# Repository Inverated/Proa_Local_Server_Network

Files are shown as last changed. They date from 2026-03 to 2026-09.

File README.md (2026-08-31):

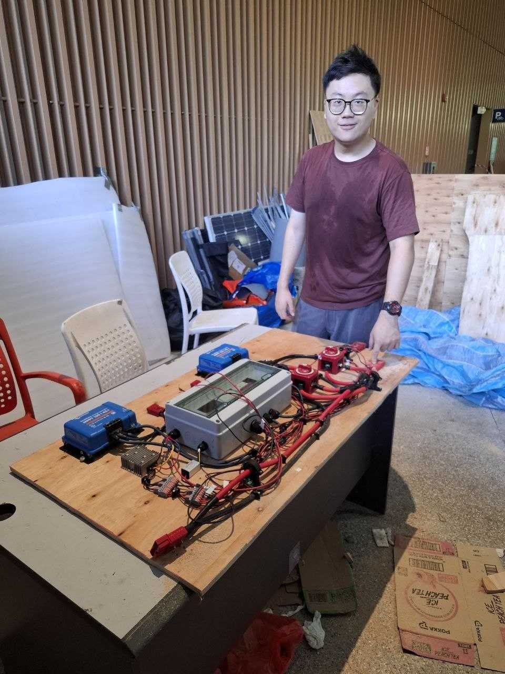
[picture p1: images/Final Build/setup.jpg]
Proa Local Server Network Hardware Setup


# Hardware

Electrical simulation used for the build can be found at [Solar Proa](https://github.com/shipshape-marine/solar-proa/tree/main/src/electrical_simulation).

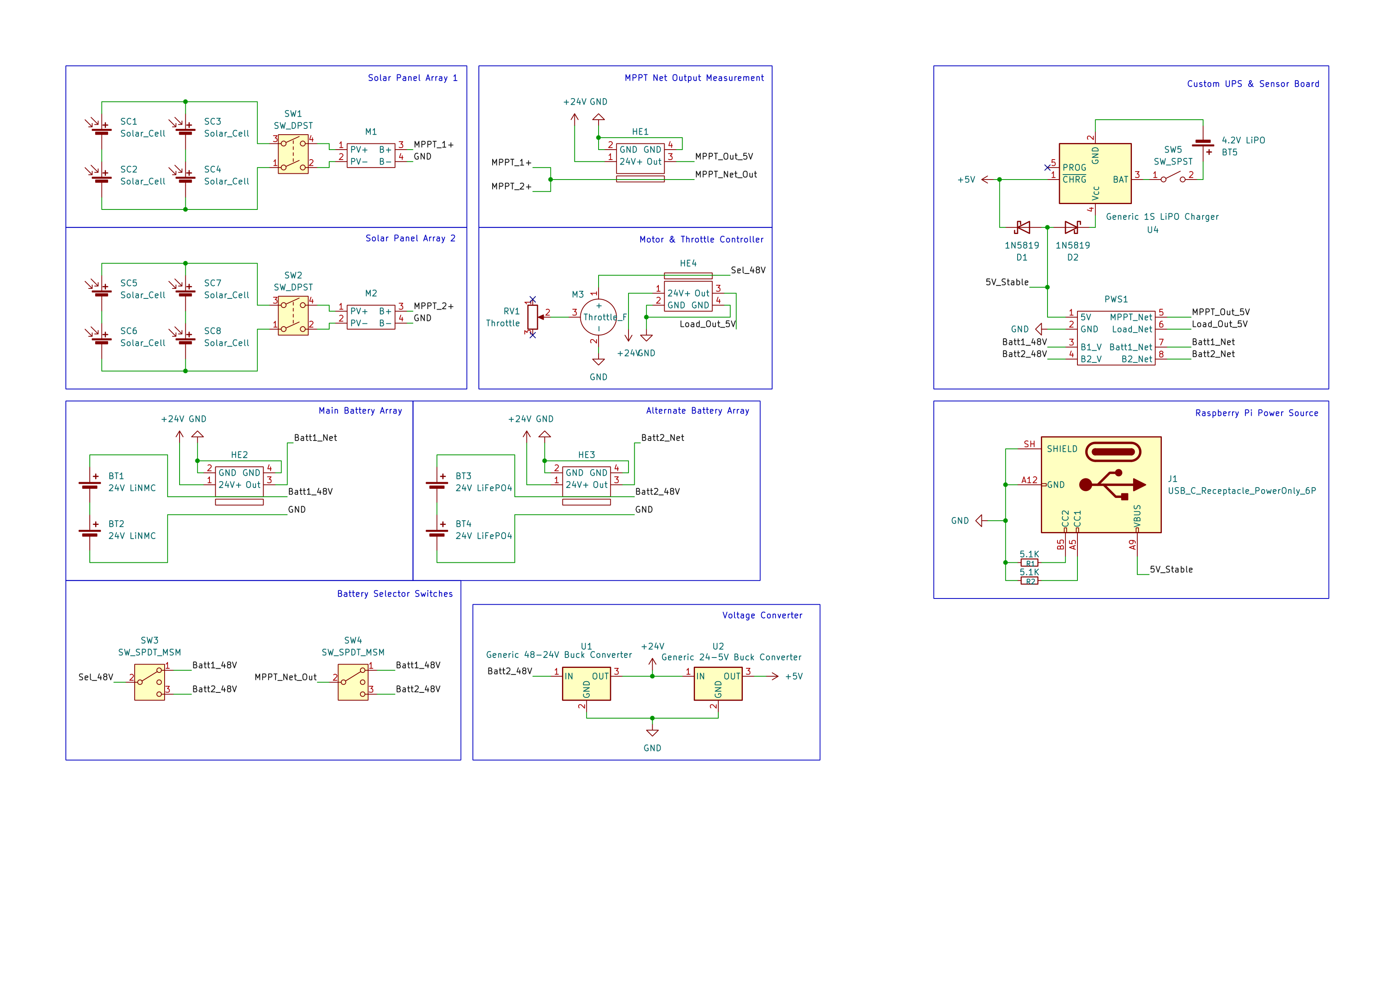
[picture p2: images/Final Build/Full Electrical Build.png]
Proa Local Server Network Schema


KiCad build file [here](./Hardware%20Schematics/ADC%20Power%20Sensor%20Design/).

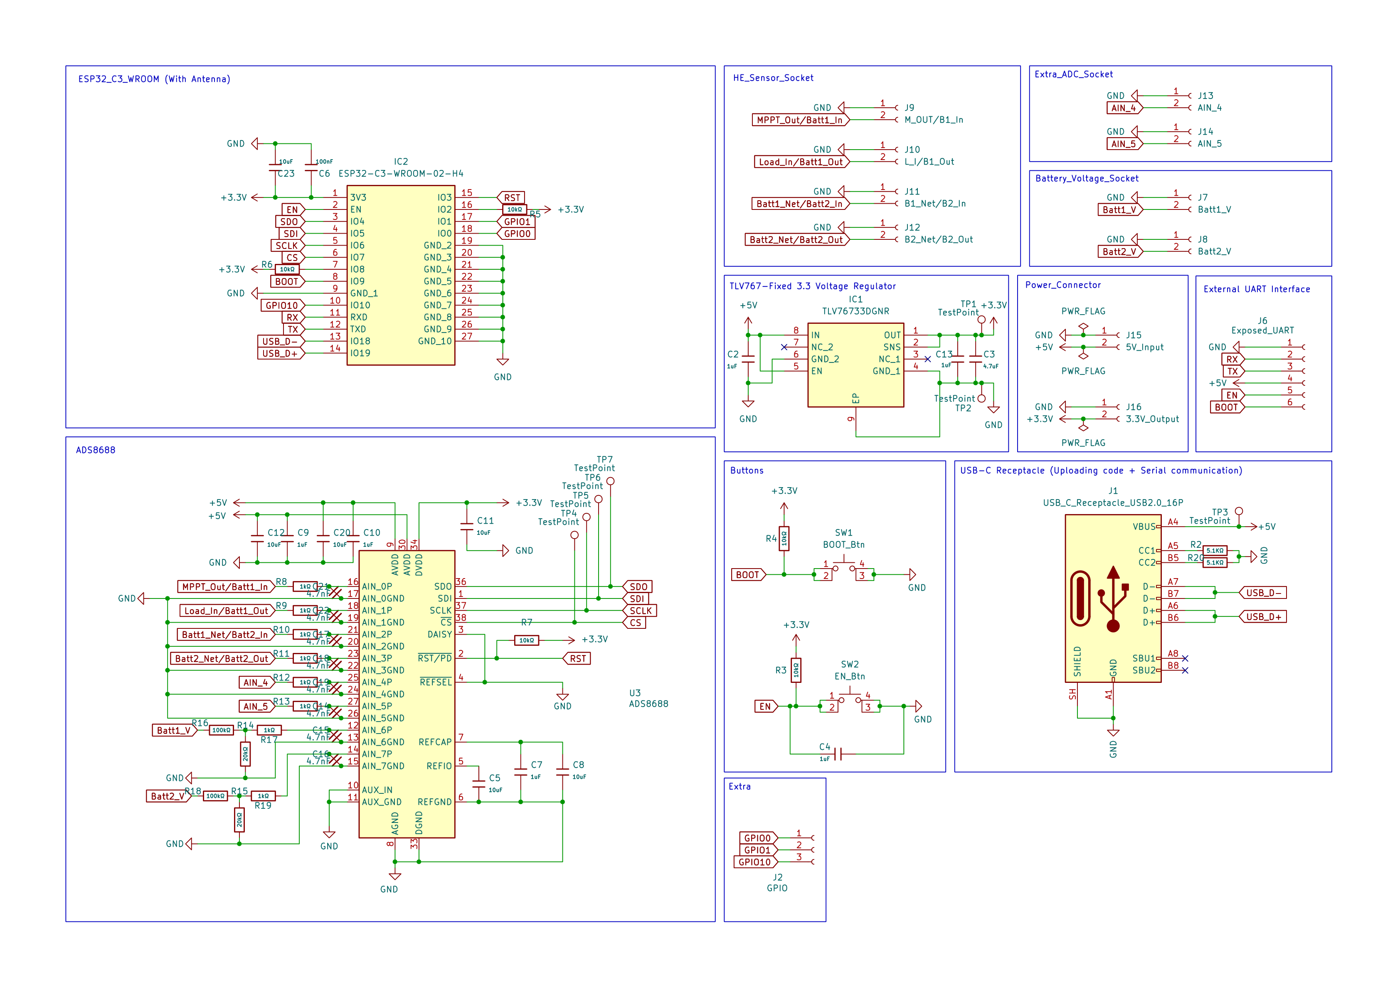
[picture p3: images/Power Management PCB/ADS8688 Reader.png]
Power Management Board


# Framework

Network of ESP32 microcontrollers with a Raspberry Pi 4 acting as a local server. ESP32 reading the sensors (slave) communicates bi-directionally via ESP-NOW where the main (Master) ESP32 sends the data to the raspberry pi via Serial communication.

ESP-NOW used for its low latency and low power consumption while being very easy to setup (<10 lines to setup + 2 function that runs when receiving or sending data), while Serial is used for its reliability and ease of use.

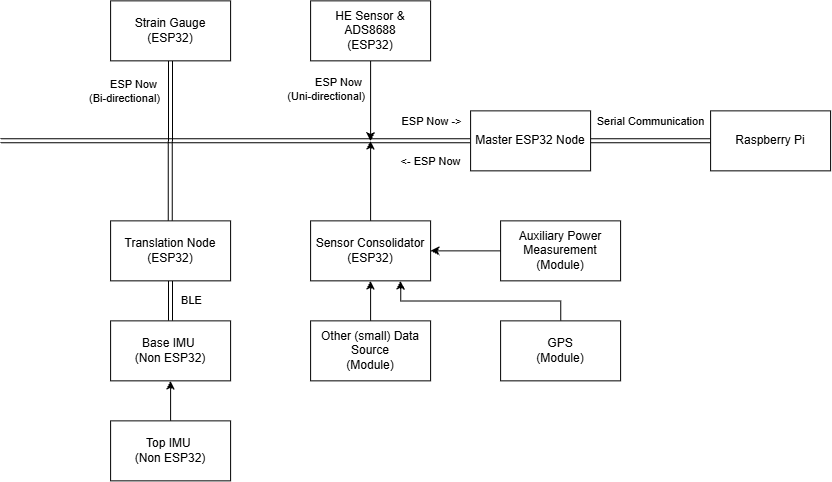
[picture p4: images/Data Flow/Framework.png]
Proa Local Server Network Framework


Both Serial and ESP-NOW allows for bi-communication, allowing the raspberry pi to send command (zeroing, start, stop, etc.) to specific ESP32s (IMU), while the ESP32s sends data to the raspberry pi at the same time.

[Template for communicating with the master node](./firmware/ESP32/template_sender_firmware//). Note that the mac address need to be changed to the master node's mac address in order for the ESP32 to send data to the master node.

# Code Structure

ExpressJs backend api + Serial reading

React frontend with MUI dashboard template

- https://github.com/mui/material-ui/tree/v9.0.1/docs/data/material/getting-started/templates/dashboard
- A shit template that mixes ts, js and tsx, jsx and poor code organisation

# Proa Local Server Network — Step by step Setup Guide

## Part 1: Running the App

1. `cd` into `PROA_LOCAL_SERVER_NETWORK`.
2. Ensure npm is installed on your system.
3. Run `npm run install:yarn`.
4. Run `yarn start:all`.
   - This automatically builds the React app and runs it with Node.js.
5. Open `http://localhost:4000` in your browser.
6. Dev panel access: username=admin   password=admin

---

## Part 2: Raspberry Pi 4 Setup (Everything else after this is for setting up on raspberry pi)

Using Raspberry Pi Lite OS for fast boot time in case of downtime.
> A UPS is included, but fast boot time and proper recovery steps are still essential.

### 2.1 Initial Setup (from a fresh install via Raspberry Pi Imager)

If ssh does not work, you may need to connect the Pi to an external screen and keyboard to enable it.
1. Connect the Pi to an external screen (micro HDMI) and keyboard.
2. Log in with the username and password created during Imager setup.
3. Enable and start SSH:
   ```bash
   sudo systemctl enable ssh
   sudo systemctl start ssh
   ```

### 2.2 SSH into the Pi from Another Computer

1. On Raspberry Pi 4 and below (check your model first), the USB-C port is power-only — you'll need an additional Ethernet cable to connect.

### 2.3 Optimize Boot Time

1. Open the quick system settings GUI to connect to a WiFi network for update purposes:
   ```bash
   sudo raspi-config
   ```
2. Disable unneeded services for a faster boot:
   ```bash
   sudo systemctl disable NetworkManager-wait-online.service
   sudo systemctl mask NetworkManager-wait-online.service
   sudo systemctl disable cloud-init-local.service
   sudo systemctl disable cloud-init-main.service
   sudo systemctl disable cloud-config.service
   sudo systemctl disable cloud-final.service
   sudo systemctl disable apt-daily-upgrade.service
   sudo systemctl disable apt-daily.service
   ```
3. Note: boot time will still be around 20 seconds.

### 2.4 Verify Network Connectivity (Before Upgrading Packages)
 
`apt full-upgrade` requires a working internet connection — check this first if you hit connection errors.
 
1. Check if Wi-Fi is scanning networks:
```bash
   sudo iwlist wlan0 scan | grep ESSID
```
2. If nothing comes back (Wi-Fi is down), bring it back up:
```bash
   sudo rfkill unblock wifi
   sudo ip link set wlan0 up
   sudo nmcli radio wifi on
   sudo systemctl restart wpa_supplicant
   sudo systemctl restart NetworkManager
```
3. Re-run the scan command from step 1 to confirm networks now appear, then proceed.

### 2.5 Download Required Packages

1. Update and install system packages:
   ```bash
   sudo apt full-upgrade
   sudo apt install git nodejs npm curl hostapd dnsmasq dhcpcd5 iptables nginx -y
   sudo npm install yarn -g
   ```
2. Install nvm and Node LTS:
   ```bash
   curl -o- https://raw.githubusercontent.com/nvm-sh/nvm/v0.40.1/install.sh | bash
   source ~/.bashrc
   nvm install --lts
   nvm use node
   ```

### 2.6 Set Up the Git Repo

1. Create a directory and clone the repo:
   ```bash
   mkdir apps
   cd apps
   git clone https://github.com/Inverated/Proa_Local_Server_Network advisor
   cd advisor/
   yarn install
   yarn start:all
   ```
2. Force-stop the process once the initial build completes.

3. Copy '.env' into proa_advisor

### 2.7 Set Up the Network (Wi-Fi Access Point)

1. Stop the AP-related services before configuring them:
   ```bash
   sudo systemctl stop hostapd
   sudo systemctl stop dnsmasq
   ```
2. Mark `wlan0` as unmanaged by NetworkManager. Edit:
   ```bash
   sudo nano /etc/NetworkManager/conf.d/unmanaged.conf
   ```
   Add:
   ```ini
   [keyfile]
   unmanaged-devices=interface-name:wlan0
   ```
3. Set a static IP for `wlan0`. Edit:
   ```bash
   sudo nano /etc/dhcpcd.conf
   ```
   Add:
   ```ini
   interface wlan0
   static ip_address=192.168.4.1/24
   nohook wpa_supplicant
   ```
4. Restart the dhcpcd service:
   ```bash
   sudo systemctl restart dhcpcd
   ```
5. Configure hostapd. Edit:
   ```bash
   sudo nano /etc/hostapd/hostapd.conf
   ```
   Add:
   ```ini
   interface=wlan0
   driver=nl80211

   ssid=Proa_II

   hw_mode=g
   channel=6

   country_code=SG

   wmm_enabled=1

   auth_algs=1
   ignore_broadcast_ssid=0

   wpa=2
   wpa_passphrase=password

   wpa_key_mgmt=WPA-PSK
   rsn_pairwise=CCMP
   ```
6. Point the hostapd daemon at that config. Edit:
   ```bash
   sudo nano /etc/default/hostapd
   ```
   Add:
   ```ini
   DAEMON_CONF="/etc/hostapd/hostapd.conf"
   ```
7. Back up and replace the dnsmasq config:
   ```bash
   sudo mv /etc/dnsmasq.conf /etc/dnsmasq.conf.orig
   sudo nano /etc/dnsmasq.conf
   ```
   Add:
   ```ini
   interface=wlan0

   dhcp-range=192.168.4.2,192.168.4.100,255.255.255.0,24h

   dhcp-option=3,192.168.4.1
   dhcp-option=6,192.168.4.1

   address=/#/192.168.4.1
   ```
8. Unmask and enable the AP services, then restart networking and start them:
   ```bash
   sudo systemctl unmask hostapd
   sudo systemctl enable hostapd
   sudo systemctl enable dnsmasq

   sudo systemctl restart wpa_supplicant
   sudo systemctl restart NetworkManager
   sudo systemctl start hostapd
   sudo systemctl start dnsmasq
   ```
9. Verify `wlan0` is running in AP mode:
    ```bash
    iw dev wlan0 info
    ```
    If the type isn't `AP`, run `sudo reboot` and check again.

10. Give access to user to run nmcli over Node
    ```bash
    sudo nano /etc/polkit-1/rules.d/50-nmcli.rules
    ```
    Add:
    ```javascript
    polkit.addRule(function(action, subject) {
        if (action.id.indexOf("org.freedesktop.NetworkManager.") === 0 &&
            subject.user == "admin") {
            return polkit.Result.YES;
        }
    });
    ```
11. Restart polkit:
    ```bash
    sudo systemctl restart polkit
    ```

### 2.9 Auto-Redirect Port 80 to the App (Port 4000)

1. Create the redirect service:
   ```bash
   sudo nano /etc/nginx/sites-available/solarproa
   ```
   Add:
   ```ini
   server {
    listen 80;
    server_name solarproa.local;

    location / {
        proxy_pass http://127.0.0.1:4000;

        proxy_set_header Host $host;
        proxy_set_header X-Real-IP $remote_addr;
        proxy_set_header X-Forwarded-For $proxy_add_x_forwarded_for;
        proxy_set_header X-Forwarded-Proto $scheme;
    }
   }
   ```
2. Enable and start it:
   ```bash
   sudo ln -s /etc/nginx/sites-available/solarproa /etc/nginx/sites-enabled/
   ```

3. Test it:
   ```bash
   sudo nginx -t
   ```

4. Restart nginx service
   ```bash
   sudo systemctl restart nginx
   ```

   When connected to the same network as the raspberry pi, go to http://solarproa.local

### 2.8 Set Up Auto-Start on Boot

1. Create the app service:
   ```bash
   sudo nano /etc/systemd/system/solarproa-advisor.service
   ```
   Add:
   ```ini
    [Unit]
    Description=Solar Proa Advisor
    After=network-online.target
    Wants=network-online.target

    [Service]
    Type=simple
    User=admin
    WorkingDirectory=/home/admin/apps/advisor/proa_advisor

    Environment=NODE_ENV=production
    Environment=NVM_DIR=/home/admin/.nvm

    ExecStart=/bin/bash -c 'source "$NVM_DIR/nvm.sh" && nvm use default && exec yarn start'

    Restart=always
    RestartSec=5

    [Install]
    WantedBy=multi-user.target
   ```
2. Enable and start it:
   ```bash
   sudo systemctl daemon-reload
   sudo systemctl enable solarproa-advisor
   sudo systemctl start solarproa-advisor
   ```
3. Check the logs:
   ```bash
   journalctl -u solarproa-advisor -f
   ```

### 2.10 Note: AP vs. Wi-Fi Receiver Mode

The Wi-Fi chip can only act as **either** an access point **or** a receiver at one time — switch back to receiving, or use an external Wi-Fi adapter.

1. Check the new Wi-Fi receiver's interface name (should be `wlan1`).
2. Connect to a network on that interface:
   ```bash
   sudo nmcli device wifi connect "YourSSID" password "YourPassword" ifname wlan1
   ```

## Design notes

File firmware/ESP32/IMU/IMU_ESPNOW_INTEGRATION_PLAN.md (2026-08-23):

# IMU ESP-NOW Integration Plan

## Problem Statement
Replace the standalone BLE-to-browser IMU monitoring system with an ESP-NOW based data path that flows through the existing master node and proa_advisor server, making IMU telemetry available in the proa_advisor_react dashboard alongside the existing power management data.

## Requirements
- Base IMU node sends 28-byte telemetry packets to the master via ESP-NOW using the existing PacketTemplate format
- Base node retains BLE central role to collect gravity data from the nRF52840 top node (unchanged)
- Master node forwards raw bytes to the server (unchanged behavior), plus maintains a `header->MAC` lookup table for routing commands back
- Server parses TELE packets, computes derivable fields, and streams IMU data to the React frontend via SSE
- Command path: server sends `TELE|command\n` over serial -> master resolves TELE->MAC -> sends command to base via ESP-NOW
- Base receives commands via ESP-NOW and handles START/STOP/ZERO/RESET_ZERO
- React frontend displays IMU telemetry in a new "Mast Monitor" page similar to the mast-monitor-pairing-display UI

## Architecture

```
Top Node (nRF52840 Sense, BLE Peripheral)
    |
    | BLE GravityPacket (gx, gy, gz, seq)
    v
Base Node (ESP32, BLE Central + ESP-NOW Sender)
    |
    | ESP-NOW 28-byte TELE packet
    v
Master Node (ESP32, ESP-NOW Hub, USB Serial)
    |
    | Serial.write(raw bytes)
    v
proa_advisor (Node.js Server)
    |
    | SSE 'imu' event
    v
proa_advisor_react (Dashboard)

Command path (reverse):
Dashboard -> POST /command/imu -> Server -> Serial "TELE|cmd\n" -> Master -> ESP-NOW -> Base
```

## Packet Structure (28 bytes)

```c
struct __attribute__((packed)) Telemetry_Payload {
  int16_t  baseRoll;            // 2 bytes - fixed point x100
  int16_t  basePitch;           // 2 bytes
  int16_t  topRoll;             // 2 bytes
  int16_t  topPitch;            // 2 bytes
  int16_t  topMinusBaseRoll;    // 2 bytes
  int16_t  topMinusBasePitch;   // 2 bytes
  int16_t  vectorAngle;         // 2 bytes
  uint16_t topSeq;              // 2 bytes
  uint8_t  status;              // 1 byte (bit0=topConnected, bit1=sensingEnabled, bit2=zeroReady)
};                              // = 17 bytes

using TelemetryPacket = PacketTemplate<Telemetry_Payload, 3>;
// header(4) + counter(2) + payload(17) + padding(3) + chksum(2) = 28 bytes
```

## Key Design Decisions
- No MAC address in packet: server identifies data by header ("TELE"), master holds header->MAC table internally for command routing
- Top node stays nRF52840 Sense (onboard IMU), BLE link to base unchanged
- Base auto-reconnects to top node every 3 seconds (no PAIR_TOP command needed)
- Commands supported: START, STOP, ZERO, RESET_ZERO
- 28-byte packet size maintained: no changes needed to PACKET_BYTES constant in serial reader
- Derivable fields computed server-side: bendMagnitude, baseMinusTopRoll, baseMinusTopPitch

## Task Breakdown

### Task 1: Base node firmware (BLE to top + ESP-NOW telemetry)
- Update `revised_base_node_v2_esp_now.ino` with new Telemetry_Payload (vectorAngle + status)
- PAD_BYTES changes from 6 to 3
- Serial debug logging for BLE connection, angle computation, ESP-NOW delivery
- Auto-start sensing for testing (sensingEnabled = true by default)
- onDataRecv stub registered for future command reception

### Task 2: Server-side TELE parser (console output)
- Create/update `imu_telemetry_parser.js` 
- Add TELE_HEADER branch in serialReader.js processBuffer()
- Parse 28-byte packet, validate checksum, convert fixed-point to float
- Compute derived fields (bendMagnitude, baseMinusTop)
- Console.log parsed telemetry for verification

### Task 3: Master node header->MAC table + command routing
- Add header->MAC lookup in OnDataRecv
- Modify checkForSerialCommands() to parse "HEADER|command\n" format
- Look up MAC from header table, call sendCommandToNode

### Task 4: Base node command reception via ESP-NOW
- Implement onDataRecv to receive commands from master
- Route to handleCommand() (START/STOP/ZERO/RESET_ZERO)
- Serial debug logging on command receipt

### Task 5: Server SSE streaming + command endpoint
- Call write_to_clients("imu", data) from parser
- Add POST /command/imu endpoint
- Update serial_writer.js to use header instead of MAC

### Task 6: React frontend - Mast Monitor page
- Add "imu" SSE event listener in Dashboard.tsx
- Create MastMonitor component with metrics, tables, status, command buttons
- Define ImuData type

### Task 7: Integration verification
- Full system test with power sensor and IMU running simultaneously
- Verify no packet corruption between types
- Test reconnection scenarios

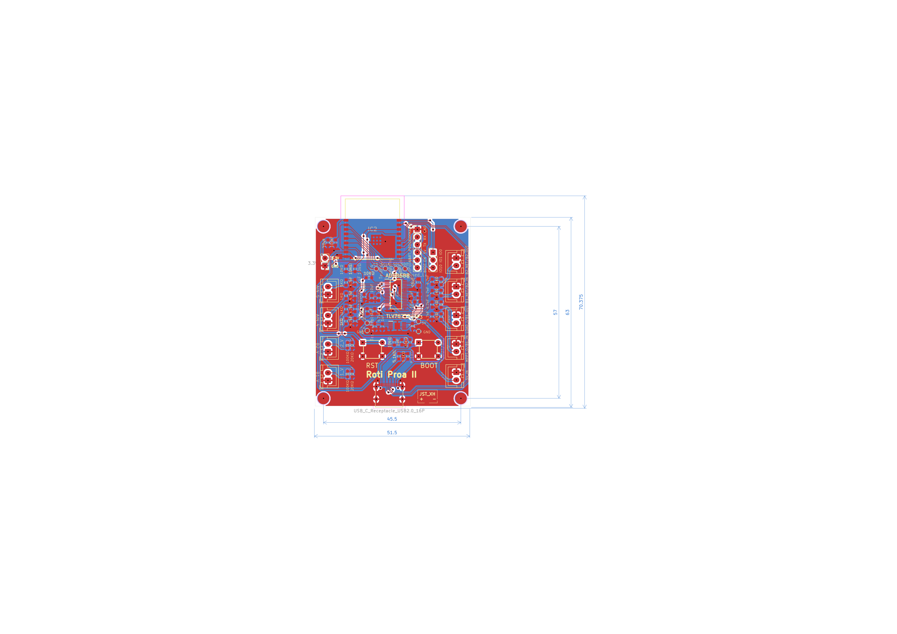
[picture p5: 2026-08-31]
images/Power Management PCB/PCB Schematic.png

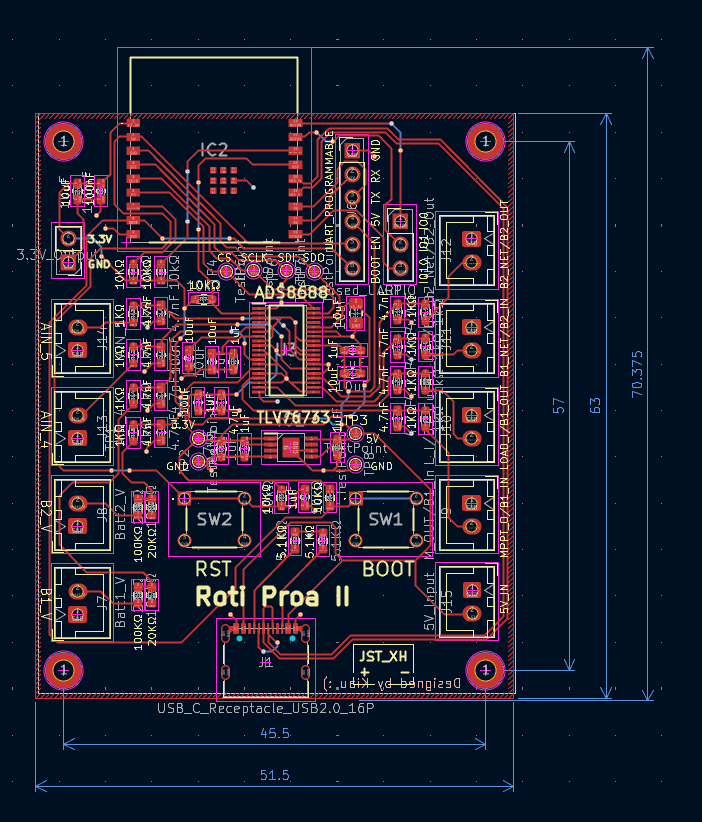
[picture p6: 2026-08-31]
Hardware Schematics/Electrical Schematics/ADC Power Sensor Design/Sensor Reader V4/Screenshot 2026-08-31 162607.png

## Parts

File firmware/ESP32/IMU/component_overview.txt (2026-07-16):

Component overview (location -> purpose)

1) IMU.ino
   Path: firmware\ESP32\IMU\IMU.ino
   Purpose: Simple BLE top-node example that reads LSM6DS3 accel, computes roll/pitch, and advertises them via a BLE characteristic (XIAO_TOP_IMU). Used for broadcasting angle packets.

2) revised_top_node.ino
   Path: mast_monitor_package\firmware\revised_top_node\revised_top_node.ino
   Purpose: Top IMU node. Reads accel, applies a low-pass gravity filter, publishes GravityPacket (gx,gy,gz,seq) over BLE to a base node at ~20Hz.

3) revised_base_node.ino
   Path: mast_monitor_package\firmware\revised_base_node\revised_base_node.ino
   Purpose: Base bridge. Reads base IMU, connects to top node over BLE, subscribes to top gravity packets, filters vectors, computes roll/pitch, zeroing, and exposes telemetry & command BLE service for a browser dashboard (CSV telemetry).

4) top_node_pairing_display.ino
   Path: mast-monitor-pairing-display\arduino\top_node_pairing_display\top_node_pairing_display.ino
   Purpose: Top node variant for pairing/display. Publishes gravity packets and periodic status string characteristic to help pairing and diagnostics.

5) base_bridge_pairing_display.ino
   Path: mast-monitor-pairing-display\arduino\base_bridge_pairing_display\base_bridge_pairing_display.ino
   Purpose: Base bridge variant supporting pairing UI. Scans/connects to top, exposes telemetry, command, and status characteristics to a browser pairing dashboard; supports PAIR/START/STOP/ZERO commands and telemetry CSV output.

6) mast_monitor_package node server
   Path: mast_monitor_package\node_app\server.js
   Purpose: Fastify server serving a simple browser dashboard (public/) and /api/log endpoints to start/stop/append CSV logs (fields: timestamp,baseRoll,basePitch,topRoll,topPitch,deltaRoll,deltaPitch,totalAngle).
   Additional: public app.js implements Web Bluetooth client to connect to XIAO_BASE_BRIDGE, render telemetry, send commands, and call the log API.

7) mast-monitor-pairing-display node server
   Path: mast-monitor-pairing-display\server.js
   Purpose: Fastify server for the pairing/display UI. Serves public UI and richer /api/log endpoints using expanded CSV_FIELDS (includes topMinusBase, bendMagnitude, vectorAngle, topSeq and status fields). Supports CSV escaping.
   Additional: public app.js implements a richer Web Bluetooth UI: pairing, status updates, telemetry parsing, and resilient log append queueing.

Notes:
- package.json files exist under both node app folders (node_app and mast-monitor-pairing-display) defining Node dependencies and start scripts.
- Main components: top IMU nodes (publish filtered gravity vector), base bridge nodes (aggregate, compute angles, expose telemetry & commands), and browser dashboards (connect via Web Bluetooth and log telemetry via local HTTP server).

BLE communication and roles:
- Top node: advertises the gravity characteristic (UUIDs starting with 19B10010/11). It is the broadcaster; it does not initiate connections to the base.
- Base node: actively scans for a device named "XIAO_TOP_IMU", connects, discovers the gravity characteristic, and subscribes to notifications. The base acts as the collector/master for the top node and also reads its own IMU.
- Collector/third device: there is no separate ESP32 that collects from both. The base node collects both top and base IMU data and exposes telemetry to a browser (XIAO_BASE_BRIDGE). The browser (web app) and optional local Node server act as the UI and log collector but are not required for the BLE link between top and base.

Commands from the web app to the ESP32 (written to the command BLE characteristic):
- START: Sent to the base node. Enables sensing and periodic telemetry output on the base. The command itself only affects the base, but effective telemetry output requires both IMUs connected and zeroed (the base will auto-zero if both IMUs are ready).
- STOP: Sent to the base node. Disables sensing and stops telemetry updates on the base. This operates on the base only (no top interaction required to process the command).
- ZERO: Sent to the base node. Captures the current pose as the zero reference for both base and top; requires both IMUs to be ready/connected so the base can read the top packet and compute a joint zero. (Requires interaction with both top and base.)
- PAIR / PAIR_TOP / SCAN: Sent to the base node (pairing-display firmware). Instructs the base to scan for and attempt to connect/pair with the top node. This is a base-initiated action that interacts with the top during pairing.
- RESET_ZERO: Sent to the base node (pairing-display firmware). Clears the stored zero state on the base so a new ZERO can be captured; does not require the top to be connected to execute (base-only).

Web app logging API calls (local Node server):
- POST /api/log/start: Create/open a new CSV log file and return its path.
- POST /api/log/stop: Close the active log file.
- POST /api/log/append: Append a telemetry row (JSON) to the active CSV log. The browser sends telemetry here after decoding BLE notifications.

Where command handling is implemented:
- revised_base_node.ino and base_bridge_pairing_display.ino: handleCommand(...) implements START/STOP/ZERO (and PAIR/RESET_ZERO in the pairing variant).
- public/app.js (both node apps): call writeCommand("START"/"STOP"/"ZERO"/"PAIR_TOP") and use the Node server /api/log endpoints for logging.

Saved at: firmware\ESP32\IMU\component_overview.txt

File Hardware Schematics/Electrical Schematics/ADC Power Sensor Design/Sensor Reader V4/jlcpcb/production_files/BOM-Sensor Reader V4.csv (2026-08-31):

Comment | Designator | Footprint | LCSC | Quantity
100kΩ | R16,R18 | R_0603_1608Metric_Pad0.98x0.95mm_HandSolder | C25803 | 2
100nF | C6 | C_0603_1608Metric_Pad1.08x0.95mm_HandSolder | C14663 | 1
10kΩ | R3,R4,R5,R6,R7 | R_0603_1608Metric_Pad0.98x0.95mm_HandSolder | C25804 | 5
10uF | C11 | C_0805_2012Metric_Pad1.18x1.45mm_HandSolder | C15850 | 1
10uF | C12,C20,C23,C5,C8 | C_0603_1608Metric_Pad1.08x0.95mm_HandSolder | C96446 | 5
1kΩ | R10,R11,R12,R13,R14,R15,R8,R9 | R_0603_1608Metric_Pad0.98x0.95mm_HandSolder | C21190 | 8
1uF | C10,C13,C2,C4,C7,C9 | C_0603_1608Metric_Pad1.08x0.95mm_HandSolder | C15849 | 6
20kΩ | R17,R19 | R_0603_1608Metric_Pad0.98x0.95mm_HandSolder | C4184 | 2
4.7nF | C14,C15,C16,C17,C18,C19,C21,C22 | C_0603_1608Metric_Pad1.08x0.95mm_HandSolder | C53987 | 8
4.7uF | C3 | C_0603_1608Metric_Pad1.08x0.95mm_HandSolder | C19666 | 1
5.1KΩ | R2,R20 | R_0603_1608Metric_Pad0.98x0.95mm_HandSolder | C25197 | 2
ADS8688 | U3 | SOP50P640X120-38N | C2670630 | 1
ESP32-C3-WROOM-02-H4 | IC2 | ESP32C3WROOM02H4 | C2944070 | 1
TLV76733DGNR | IC1 | SOP65P490X110-9N | C2873382 | 1
USB_C_Receptacle_USB2.0_16P | J1 | USB_C_Receptacle_XKB_U262-16XN-4BVC11 | C2988369 | 1
TestPoint | TP2 | TestPoint_Pad_D1.0mm |  | 1
TestPoint | TP1 | TestPoint_Pad_D1.0mm |  | 1
Exposed_UART | J6 | PinHeader_1x06_P2.54mm_Vertical |  | 1
TestPoint | TP8 | TestPoint_Pad_D1.0mm |  | 1
EN_Btn | SW2 | TS0266100BK100LCRD |  | 1
BOOT_Btn | SW1 | TS0266100BK100LCRD |  | 1
TestPoint | TP3 | TestPoint_Pad_D1.0mm |  | 1
3.3V_Output | J16 | PinHeader_1x02_P2.54mm_Vertical |  | 1
AIN_4 | J13 | JST_XH_B2B-XH-A_1x02_P2.50mm_Vertical |  | 1
L_I/B1_Out | J10 | JST_XH_B2B-XH-A_1x02_P2.50mm_Vertical |  | 1
TestPoint | TP4 | TestPoint_Pad_D1.0mm |  | 1
TestPoint | TP7 | TestPoint_Pad_D1.0mm |  | 1
M_OUT/B1_In | J9 | JST_XH_B2B-XH-A_1x02_P2.50mm_Vertical |  | 1
Batt2_V | J8 | JST_XH_B2B-XH-A_1x02_P2.50mm_Vertical |  | 1
Batt1_V | J7 | JST_XH_B2B-XH-A_1x02_P2.50mm_Vertical |  | 1
5V_Input | J15 | JST_XH_B2B-XH-A_1x02_P2.50mm_Vertical |  | 1
B1_Net/B2_In | J11 | JST_XH_B2B-XH-A_1x02_P2.50mm_Vertical |  | 1
B2_Net/B2_Out | J12 | JST_XH_B2B-XH-A_1x02_P2.50mm_Vertical |  | 1
AIN_5 | J14 | JST_XH_B2B-XH-A_1x02_P2.50mm_Vertical |  | 1
TestPoint | TP6 | TestPoint_Pad_D1.0mm |  | 1
TestPoint | TP5 | TestPoint_Pad_D1.0mm |  | 1
GPIO | J2 | PinHeader_1x03_P2.54mm_Vertical |  | 1

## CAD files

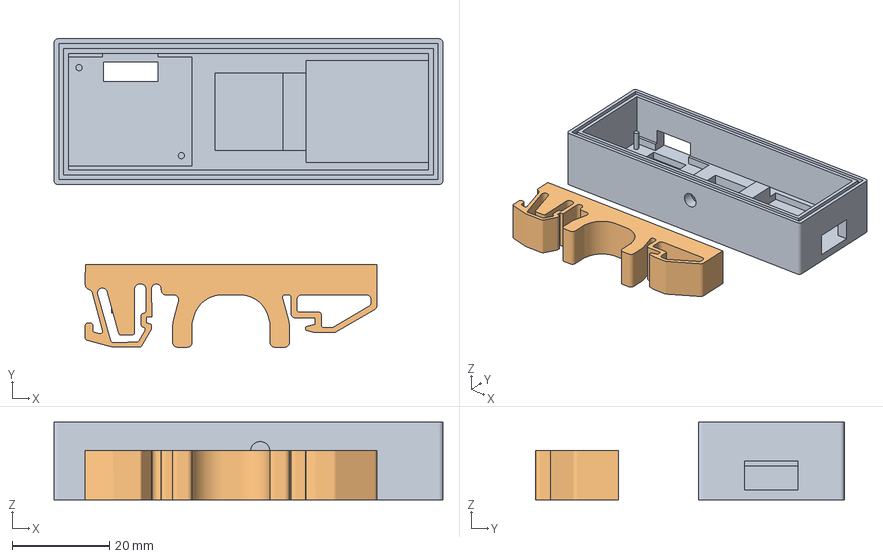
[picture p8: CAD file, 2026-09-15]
Hardware Schematics/3D Print Files/External gps sensor enclosure.3mf
80.0 x 63.5 x 16.0 mm
External gps sensor enclosure
Sub-merged Körper

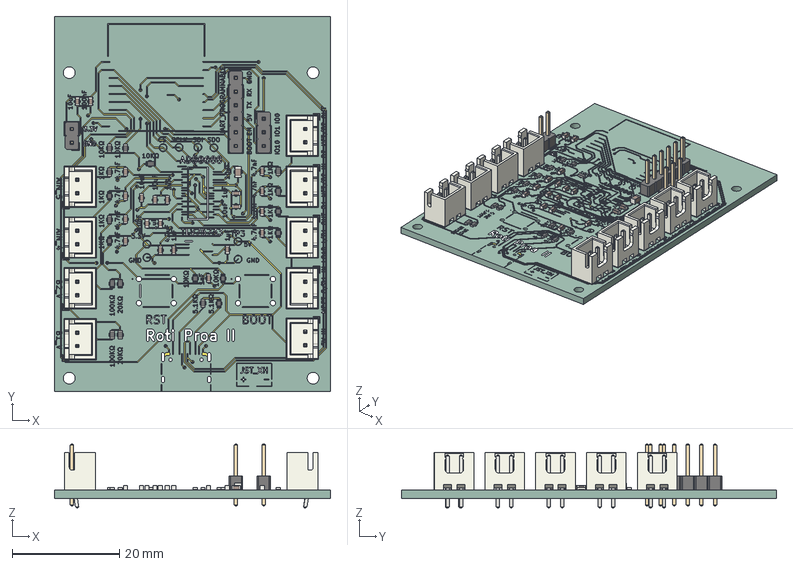
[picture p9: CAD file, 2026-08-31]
Hardware Schematics/ADC Power Sensor Design/Sensor Reader V4/.step
51.5 x 70.0 x 11.9 mm
C_0603_1608Metric x 21
R_0603_1608Metric x 19
C_0805_2012Metric
JST_XH_B2B-XH-A_1x02_P2.50mm_Vertical x 9
PinHeader_1x06_P2.54mm_Vertical
PinHeader_1x03_P2.54mm_Vertical
PinHeader_1x02_P2.54mm_Vertical
Sensor Reader V4_copper
Sensor Reader V4_via
Sensor Reader V4_silkscreen x 2
Sensor Reader V4_PCB

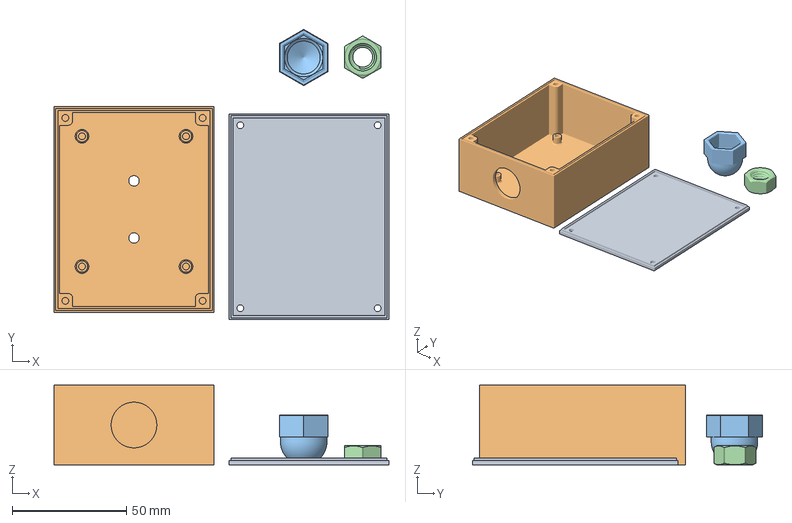
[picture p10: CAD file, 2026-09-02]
Hardware Schematics/3D Print Files/Ads8688 Enclosure.3mf
146.6 x 127.0 x 35.0 mm
NUT_CAP_M10.STP
m10

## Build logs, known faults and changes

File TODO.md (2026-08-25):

1. GPS Module integration and routing display
2. External controller? using esp32 control box
3. Remove content from original downloaded template

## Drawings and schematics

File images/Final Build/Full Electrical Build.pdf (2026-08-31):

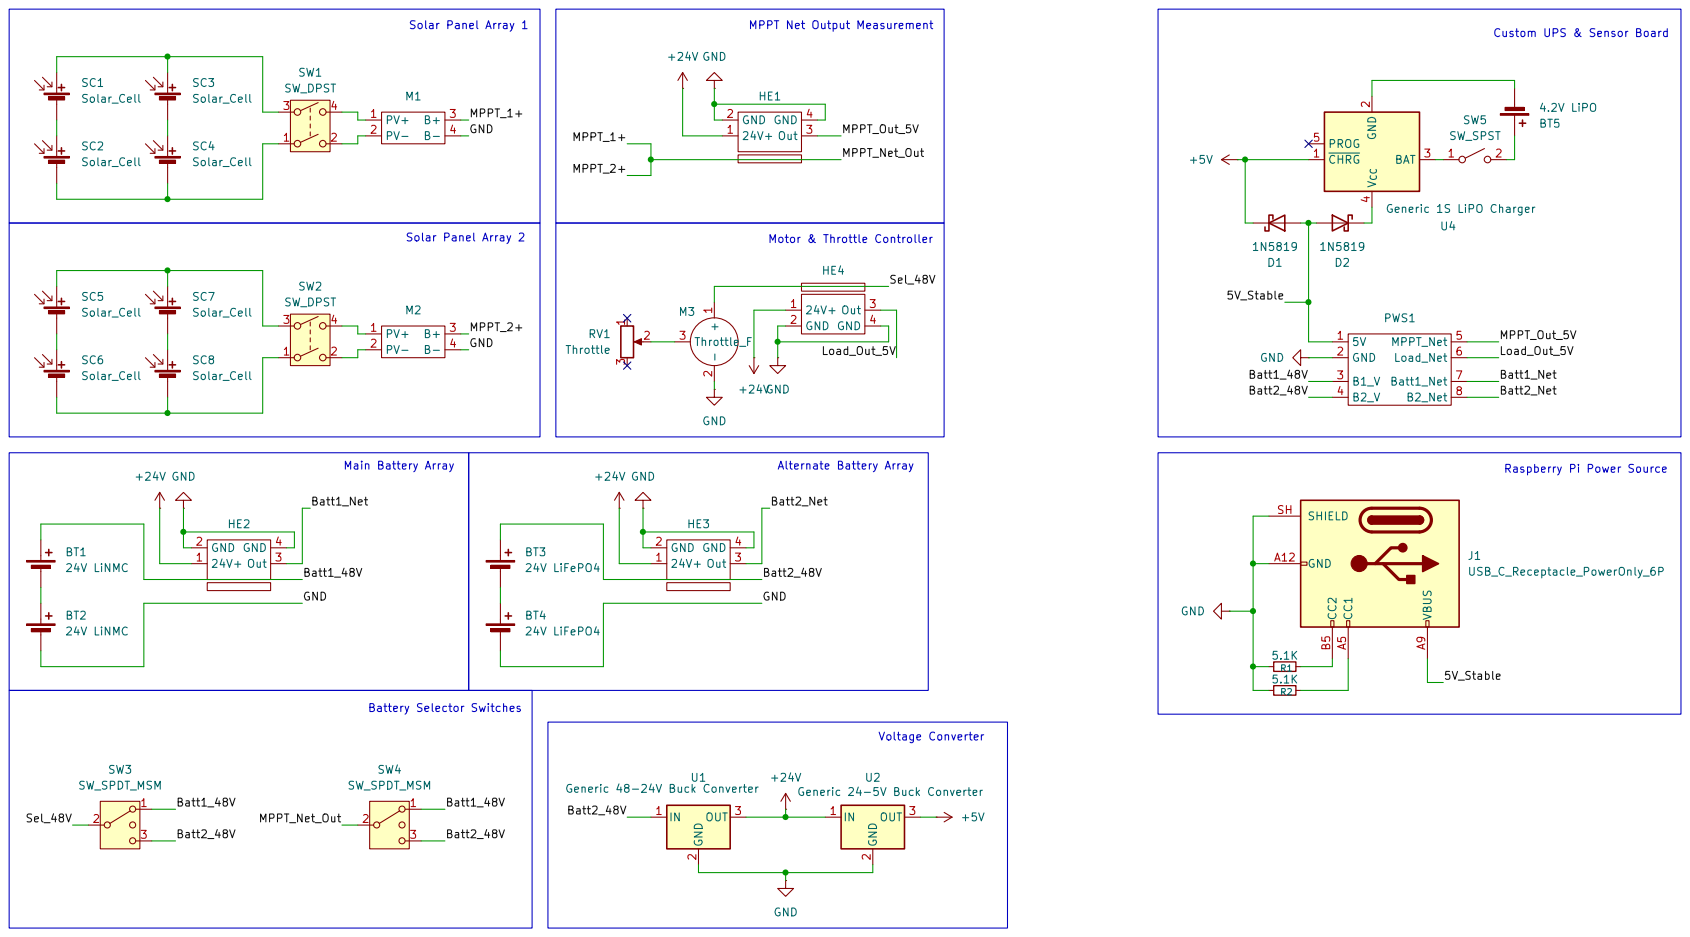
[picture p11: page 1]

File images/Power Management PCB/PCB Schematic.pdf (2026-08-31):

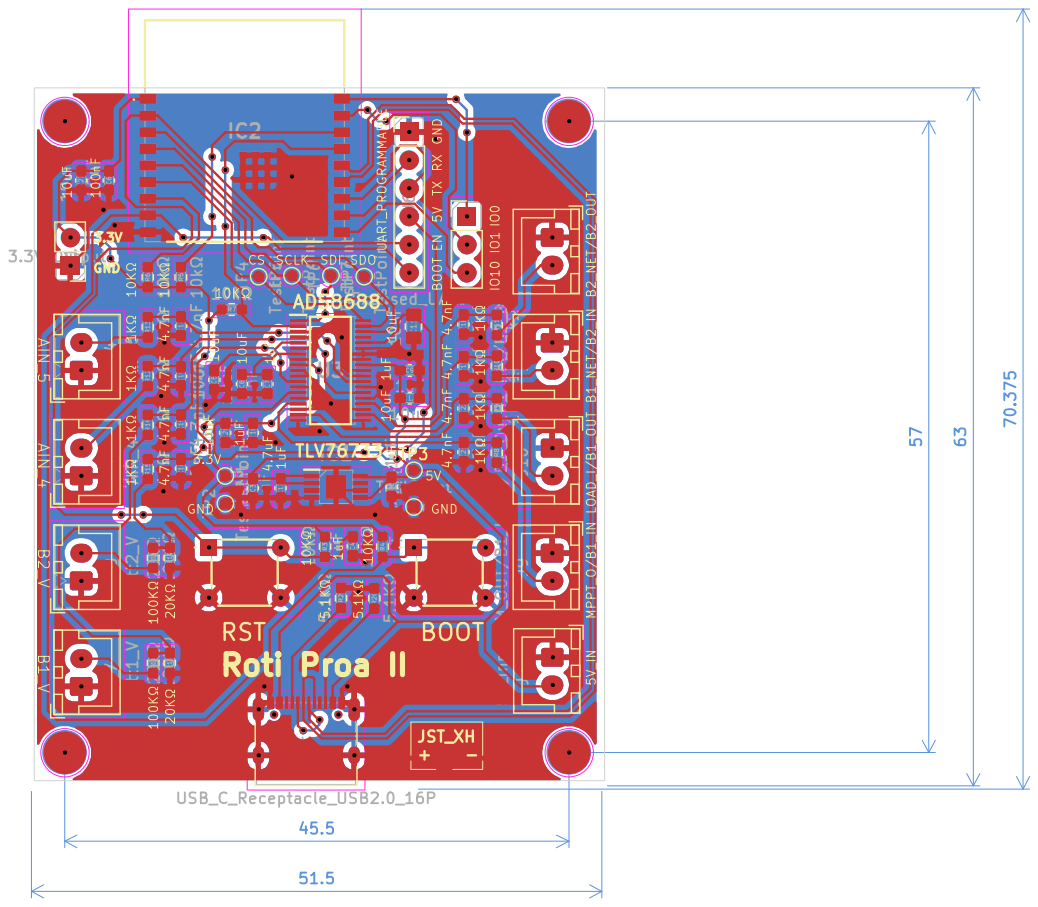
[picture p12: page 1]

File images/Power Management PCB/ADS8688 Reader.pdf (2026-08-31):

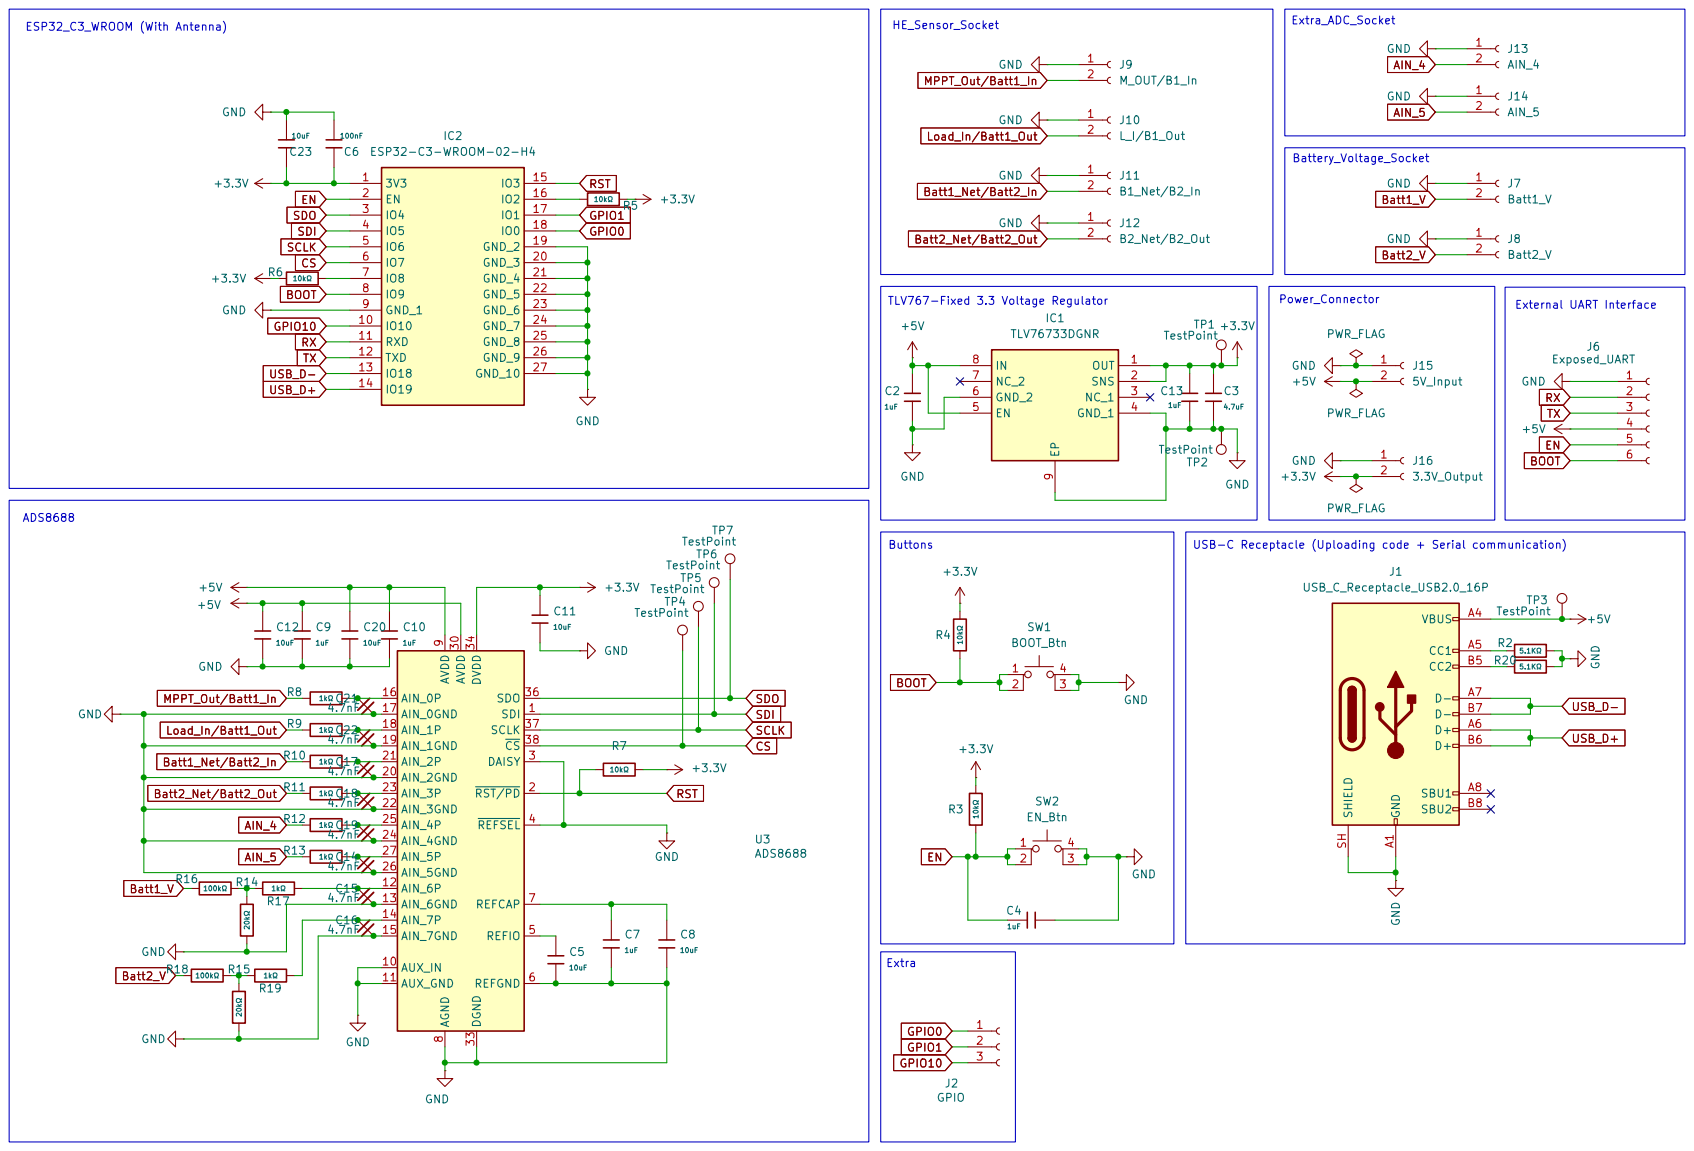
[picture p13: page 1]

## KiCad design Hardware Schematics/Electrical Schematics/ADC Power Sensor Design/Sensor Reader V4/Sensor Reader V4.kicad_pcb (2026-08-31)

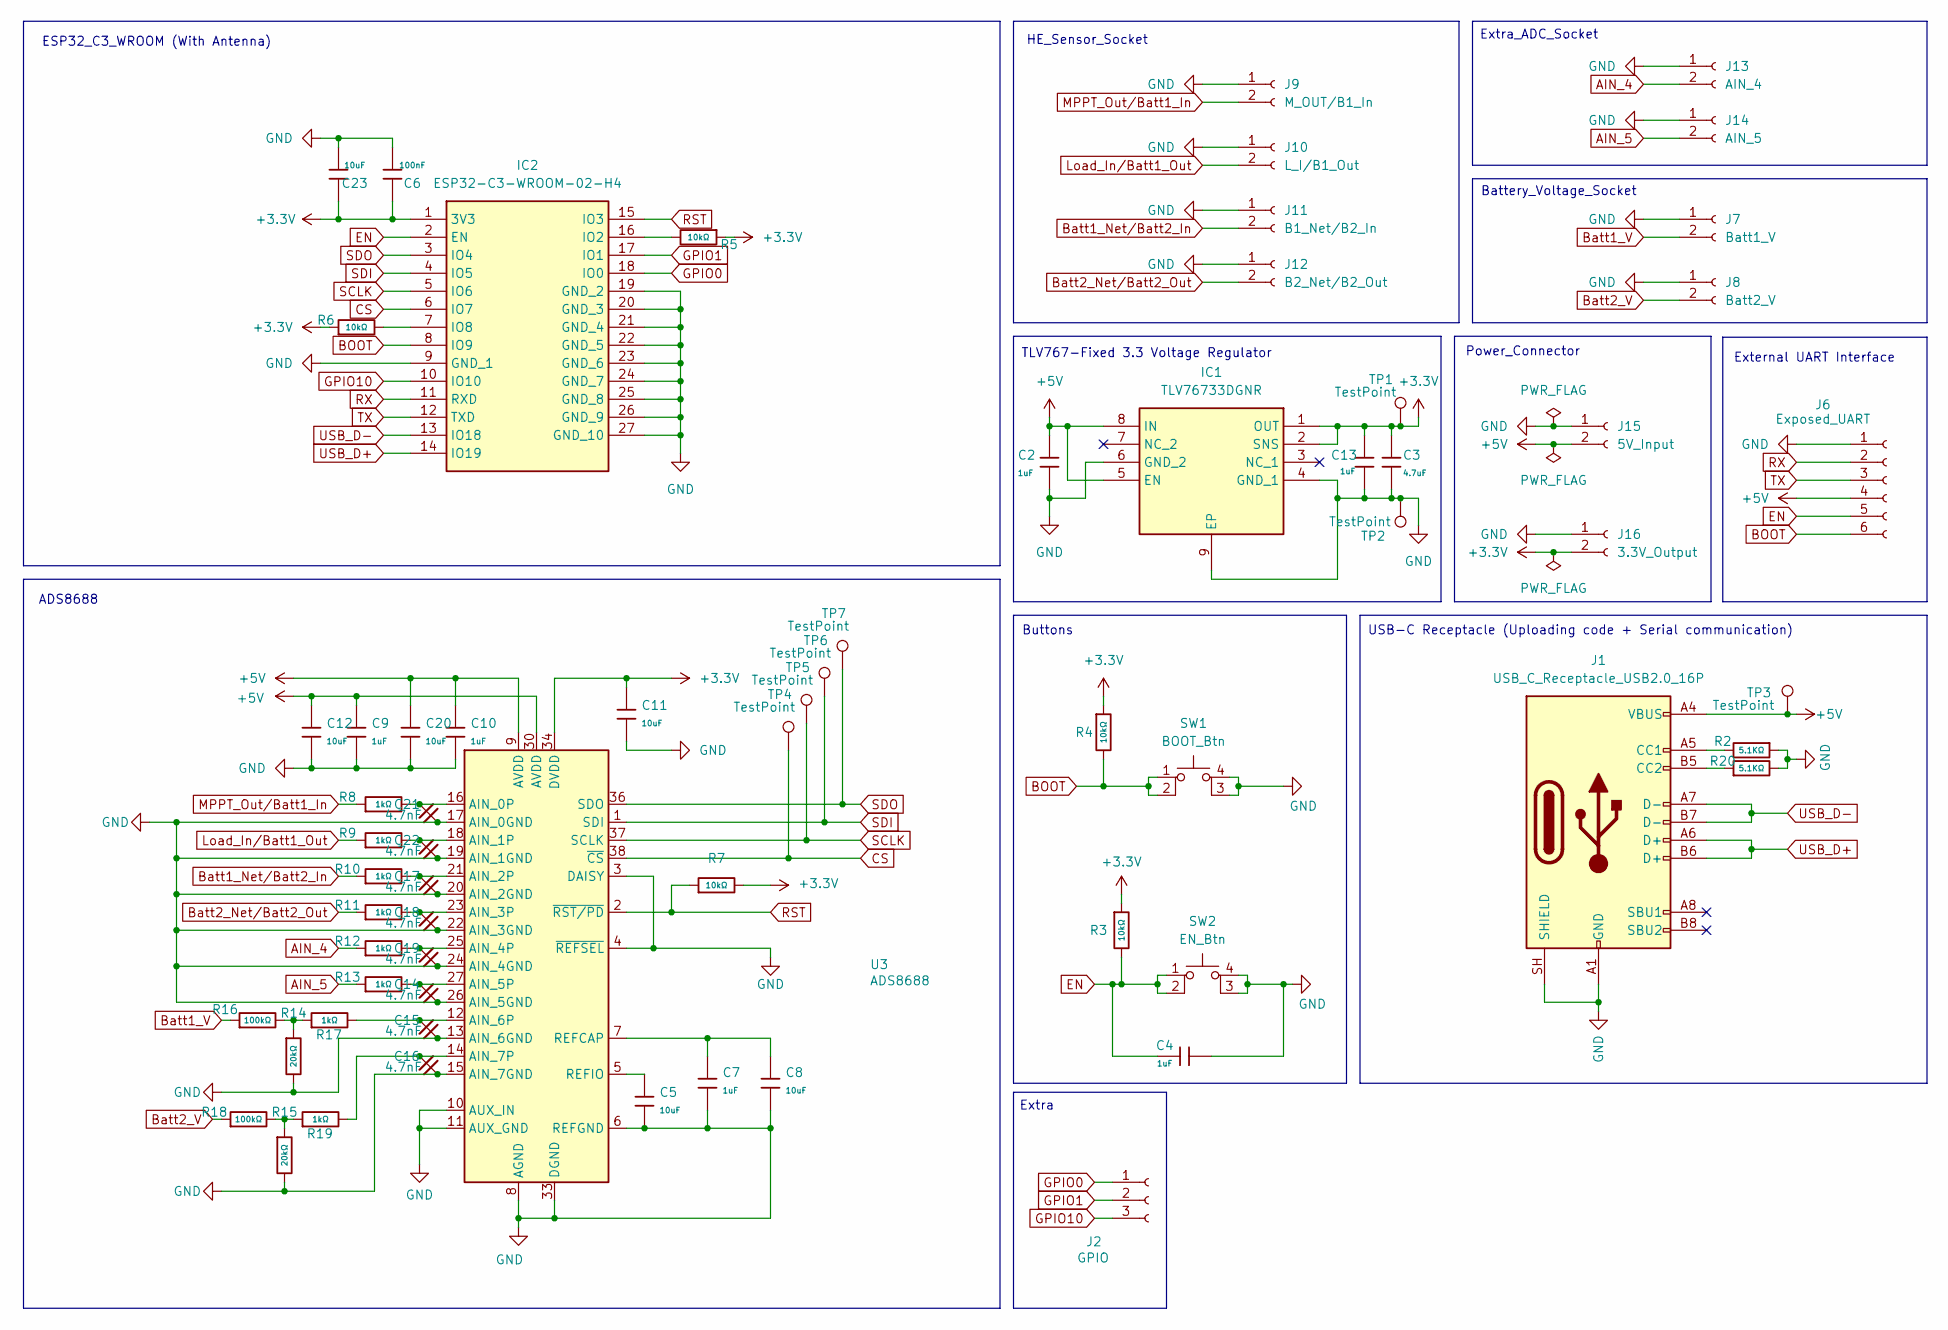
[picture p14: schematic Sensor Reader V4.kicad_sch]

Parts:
C2, C13: 1uF; C_0603_1608Metric_Pad1.08x0.95mm_HandSolder; Voltage Rated 6.3V; Tolerance ±20%; Part CL21A476MQYNNNE; LCSC C16780
C3: 4.7uF; C_0603_1608Metric_Pad1.08x0.95mm_HandSolder; Voltage Rated 16V; Tolerance ±10%; Part CL10A475KO8NNNC; LCSC C19666
C4: 1uF; C_0603_1608Metric_Pad1.08x0.95mm_HandSolder; Voltage Rated 50V; Tolerance ±10%; Part CC0603KRX7R9BB104; LCSC C14663
C5, C12, C20: 10uF; C_0603_1608Metric_Pad1.08x0.95mm_HandSolder; Voltage Rated 50V; Tolerance ±10%; Part 0603B103K500NT; LCSC C57112
C6: 100nF; C_0603_1608Metric_Pad1.08x0.95mm_HandSolder; Voltage Rated 50V; Tolerance ±10%; Part CC0603KRX7R9BB104; LCSC C14663
C7: 1uF; C_0603_1608Metric_Pad1.08x0.95mm_HandSolder; Voltage Rated 50V; Tolerance ±10%; Part CL10A105KB8NNNC; LCSC C15849
C8: 10uF; C_0603_1608Metric_Pad1.08x0.95mm_HandSolder; Voltage Rated 50V; Tolerance ±10%; Part CL10A105KB8NNNC; LCSC C15849
C9, C10: 1uF; C_0603_1608Metric_Pad1.08x0.95mm_HandSolder; Voltage Rated 50V; Tolerance ±10%; Part 0603B103K500NT; LCSC C57112
C11: 10uF; C_0805_2012Metric_Pad1.18x1.45mm_HandSolder; Voltage Rated 50V; Tolerance ±10%; Part 0603B103K500NT; LCSC C57112
C14, C15, C16, C17, C18, C19, C21, C22: 4.7nF; C_0603_1608Metric_Pad1.08x0.95mm_HandSolder
C23: 10uF; C_0603_1608Metric_Pad1.08x0.95mm_HandSolder; Voltage Rated 50V; Tolerance ±10%; Part CC0603KRX7R9BB104; LCSC C14663
IC1: TLV76733DGNR; SOP65P490X110-9N; Mouser Part Number 595-TLV76733DGNR
IC2: ESP32-C3-WROOM-02-H4; ESP32C3WROOM02H4; Mouser Part Number 356-ESP32C3WROOM02H4
J1: USB_C_Receptacle_USB2.0_16P; USB_C_Receptacle_XKB_U262-16XN-4BVC11
J2: GPIO; PinHeader_1x03_P2.54mm_Vertical
J6: Exposed_UART; PinHeader_1x06_P2.54mm_Vertical
J7: Batt1_V; JST_XH_B2B-XH-A_1x02_P2.50mm_Vertical
J8: Batt2_V; JST_XH_B2B-XH-A_1x02_P2.50mm_Vertical
J9: M_OUT/B1_In; JST_XH_B2B-XH-A_1x02_P2.50mm_Vertical
J10: L_I/B1_Out; JST_XH_B2B-XH-A_1x02_P2.50mm_Vertical
J11: B1_Net/B2_In; JST_XH_B2B-XH-A_1x02_P2.50mm_Vertical
J12: B2_Net/B2_Out; JST_XH_B2B-XH-A_1x02_P2.50mm_Vertical
J13: AIN_4; JST_XH_B2B-XH-A_1x02_P2.50mm_Vertical
J14: AIN_5; JST_XH_B2B-XH-A_1x02_P2.50mm_Vertical
J15: 5V_Input; JST_XH_B2B-XH-A_1x02_P2.50mm_Vertical
J16: 3.3V_Output; PinHeader_1x02_P2.54mm_Vertical
R2, R20: 5.1KΩ; R_0603_1608Metric_Pad0.98x0.95mm_HandSolder; Overload Voltage (Max) 75V; Tolerance ±1%; Part 0603WAF510KT5E; LCSC C25197
R3, R4, R5, R6, R7: 10kΩ; R_0603_1608Metric_Pad0.98x0.95mm_HandSolder; Overload Voltage (Max) 75V; Tolerance ±1%; Part 0603WAF1002T5E; LCSC C25804
R8, R9, R10, R11, R12, R13, R14, R15: 1kΩ; R_0603_1608Metric_Pad0.98x0.95mm_HandSolder; Overload Voltage (Max) 75V; Tolerance ±1%; Part 0603WAF1001T5E; LCSC C21190
R16, R18: 100kΩ; R_0603_1608Metric_Pad0.98x0.95mm_HandSolder; Overload Voltage (Max) 75V; Tolerance ±1%; Part 0603WAF1003T5E; LCSC C25803
R17, R19: 20kΩ; R_0603_1608Metric_Pad0.98x0.95mm_HandSolder; Overload Voltage (Max) 75V; Tolerance ±1%; Part 0603WAF2002T5E; LCSC C4184
SW1: BOOT_Btn; TS0266100BK100LCRD
SW2: EN_Btn; TS0266100BK100LCRD
TP1, TP2, TP3, TP4, TP5, TP6, TP7: TestPoint; TestPoint_Pad_D1.0mm
U3: ADS8688; SOP50P640X120-38N

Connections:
+3.3V: C3.1, C6.1, C11.1, C13.1, C23.1, IC1.1 (OUT), IC1.2 (SNS), IC2.1 (3V3), J16.2, R3.1, R4.1, R5.1, R6.1, R7.2, TP1.1 (1_1), U3.34 (DVDD)
+5V: C2.1, C9.1, C10.1, C12.1, C20.1, IC1.5 (EN), IC1.8 (IN), J1.A4 (VBUS), J1.A9 (VBUS), J1.B4 (VBUS), J1.B9 (VBUS), J6.4, J15.2, TP3.1 (1_1), U3.9 (AVDD), U3.30 (AVDD)
AIN_4: J13.2, R12.1
AIN_5: J14.2, R13.1
BOOT: IC2.8 (IO9), J6.6, R4.2, SW1.1, SW1.2
Batt1_Net/Batt2_In: J11.2, R10.1
Batt1_V: J7.2, R16.1
Batt2_Net/Batt2_Out: J12.2, R11.1
Batt2_V: J8.2, R18.1
CS: IC2.6 (IO7), TP4.1 (1_1), U3.38 (~CS)
EN: C4.1, IC2.2 (EN), J6.5, R3.2, SW2.1, SW2.2
GND: C2.2, C3.2, C4.2, C5.2, C6.2, C7.2, C8.2, C9.2, C10.2, C11.2, C12.2, C13.2, C14.1, C15.1, C16.1, C17.1, C18.1, C19.1, C20.2, C21.1, C22.1, C23.2, IC1.4 (GND_1), IC1.6 (GND_2), IC1.9 (EP), IC2.9 (GND_1), IC2.19 (GND_2), IC2.20 (GND_3), IC2.21 (GND_4), IC2.22 (GND_5), IC2.23 (GND_6), IC2.24 (GND_7), IC2.25 (GND_8), IC2.26 (GND_9), IC2.27 (GND_10), J1.A1 (GND), J1.A12 (GND), J1.B1 (GND), J1.B12 (GND), J1.SH (SHIELD), J6.1, J7.1, J8.1, J9.1, J10.1, J11.1, J12.1, J13.1, J14.1, J15.1, J16.1, R2.1, R17.2, R19.2, R20.2, SW1.3 (K), SW1.4 (A), SW2.3 (K), SW2.4 (A), TP2.1 (1_1), U3.3 (DAISY), U3.4 (~REFSEL), U3.6 (REFGND), U3.8 (AGND), U3.10 (AUX_IN), U3.11 (AUX_GND), U3.13 (AIN_6GND), U3.15 (AIN_7GND), U3.17 (AIN_0GND), U3.19 (AIN_1GND), U3.20 (AIN_2GND), U3.22 (AIN_3GND), U3.24 (AIN_4GND), U3.26 (AIN_5GND), U3.28 (AGND), U3.29 (AGND), U3.31 (AGND), U3.32 (AGND), U3.33 (DGND); also elsewhere on the board
GPIO0: IC2.18 (IO0), J2.1
GPIO1: IC2.17 (IO1), J2.2
GPIO10: IC2.10 (IO10), J2.3
Load_In/Batt1_Out: J10.2, R9.1
MPPT_Out/Batt1_In: J9.2, R8.1
unnamed: IC2.16 (IO2), R5.2
unnamed: IC2.7 (IO8), R6.2
unnamed: J1.A5 (CC1), R2.2
unnamed: J1.B5 (CC2), R20.1
unnamed: R14.1, R16.2, R17.1
unnamed: R15.1, R18.2, R19.1
unnamed: C21.2, R8.2, U3.16 (AIN_0P)
unnamed: C22.2, R9.2, U3.18 (AIN_1P)
unnamed: C17.2, R10.2, U3.21 (AIN_2P)
unnamed: C18.2, R11.2, U3.23 (AIN_3P)
unnamed: C19.2, R12.2, U3.25 (AIN_4P)
unnamed: C14.2, R13.2, U3.27 (AIN_5P)
unnamed: C15.2, R14.2, U3.12 (AIN_6P)
unnamed: C16.2, R15.2, U3.14 (AIN_7P)
unnamed: C7.1, C8.1, U3.7 (REFCAP)
unnamed: C5.1, U3.5 (REFIO)
RST: IC2.15 (IO3), R7.1, U3.2 (~RST/PD)
RX: IC2.11 (RXD), J6.2
SCLK: IC2.5 (IO6), TP5.1 (1_1), U3.37 (SCLK)
SDI: IC2.4 (IO5), TP6.1 (1_1), U3.1 (SDI)
SDO: IC2.3 (IO4), TP7.1 (1_1), U3.36 (SDO)
TX: IC2.12 (TXD), J6.3
USB_D+: IC2.14 (IO19), J1.A6 (D+), J1.B6 (D+)
USB_D-: IC2.13 (IO18), J1.A7 (D-), J1.B7 (D-)

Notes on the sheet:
Buttons
USB-C Receptacle (Uploading code + Serial communication)
External UART Interface
Power_Connector
HE_Sensor_Socket
Extra
ESP32_C3_WROOM (With Antenna)
Extra_ADC_Socket
TLV767-Fixed 3.3 Voltage Regulator
ADS8688
Battery_Voltage_Socket

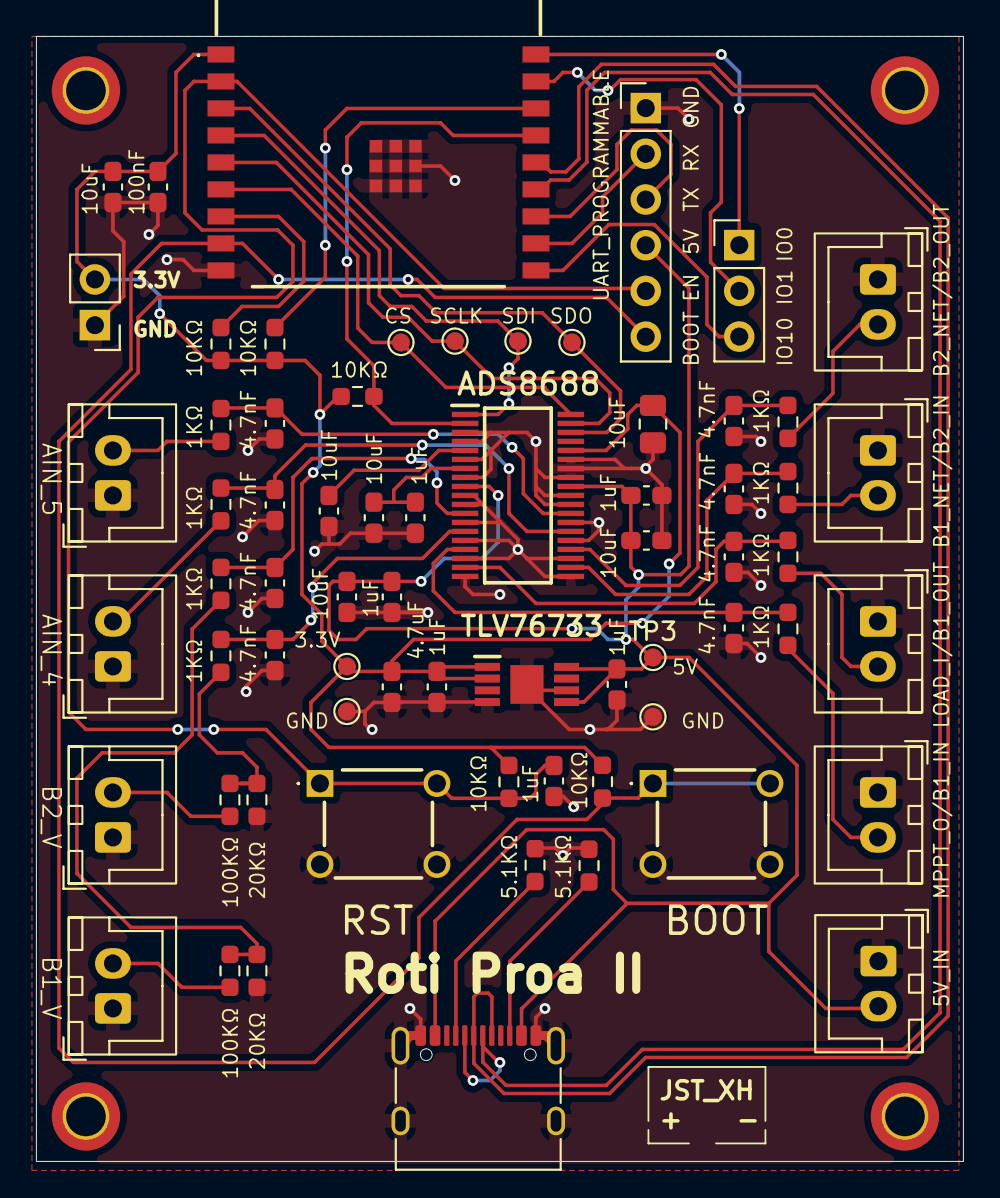
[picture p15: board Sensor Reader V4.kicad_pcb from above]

Board: 2 copper layers, 51.5 x 62.5 mm, 67 parts (0 on the bottom side), 41 nets.

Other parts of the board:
TP8: TestPoint; TestPoint_Pad_D1.0mm

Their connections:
GND: TP8.1 (1_1); also elsewhere on the board

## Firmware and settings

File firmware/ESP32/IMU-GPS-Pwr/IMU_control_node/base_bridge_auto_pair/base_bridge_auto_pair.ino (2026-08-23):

/*
 * base_bridge_auto_pair.ino
 * 
 * Seeed XIAO nRF52840 Sense - Base Bridge (Auto-Pair Edition)
 * 
 * This node:
 *  - Has its own IMU (base of mast)
 *  - AUTO-SCANS and connects to the top node (XIAO_TOP_IMU) via BLE central
 *    No "PAIR" command is needed; it scans on boot and reconnects automatically.
 *  - Advertises a BLE peripheral service so an ESP32 (instead of a PC/browser)
 *    can connect and receive telemetry notifications.
 * 
 * The telemetry characteristic sends a compact 17-byte binary struct (TelemetryPacket)
 * at 20 Hz. Angles are int16 fixed-point (×100 = 0.01° resolution).
 * Derived values (bendMagnitude, baseMinusTop) are computed on the receiver.
 * 
 * Commands accepted via BLE write characteristic:
 *   START       - Enable telemetry output
 *   STOP        - Disable telemetry output
 *   ZERO        - Re-zero the current pose
 *   RESET_ZERO  - Clear zero state
 */

#include <ArduinoBLE.h>
#include "LSM6DS3.h"
#include "Wire.h"
#include <math.h>

// Seeed XIAO nRF52840 Sense IMU at the bottom/base of the mast.
LSM6DS3 myIMU(I2C_MODE, 0x6A);

// Must match the top node packet exactly.
struct GravityPacket {
  float gx;
  float gy;
  float gz;
  uint32_t seq;
};

// Compact telemetry packet sent to ESP32 receiver via BLE notify.
// Angles stored as int16 fixed-point (×100), giving 0.01° resolution, ±327.67° range.
// Derived values (bendMagnitude, baseMinusTop) are computed on the receiver side.
const float ANGLE_SCALE = 100.0f;

struct __attribute__((packed)) TelemetryPacket {
  int16_t  baseRoll;           // 2 bytes - fixed point ×100
  int16_t  basePitch;          // 2 bytes
  int16_t  topRoll;            // 2 bytes
  int16_t  topPitch;           // 2 bytes
  int16_t  topMinusBaseRoll;   // 2 bytes
  int16_t  topMinusBasePitch;  // 2 bytes
  int16_t  vectorAngle;        // 2 bytes
  uint16_t topSeq;             // 2 bytes
  uint8_t  status;             // 1 byte: bit0=topConnected, bit1=sensingEnabled, bit2=zeroReady
};
// sizeof(TelemetryPacket) = 17 bytes

// ---------- BLE Peripheral Service (for ESP32 client to connect) ----------
BLEService espService("7A100000-3E2D-4B6A-9F10-112233445566");

BLECharacteristic telemetryChar(
  "7A100001-3E2D-4B6A-9F10-112233445566",
  BLERead | BLENotify,
  sizeof(TelemetryPacket)
);

BLEStringCharacteristic commandChar(
  "7A100002-3E2D-4B6A-9F10-112233445566",
  BLEWrite | BLEWriteWithoutResponse,
  40
);

BLEStringCharacteristic statusChar(
  "7A100003-3E2D-4B6A-9F10-112233445566",
  BLERead | BLENotify,
  160
);

// ---------- BLE Central Link: base bridge -> top IMU node ----------
BLEDevice topPeripheral;
BLECharacteristic topGravityCharacteristic;

const char TOP_NODE_NAME[] = "XIAO_TOP_IMU";
const char BASE_NODE_NAME[] = "XIAO_BASE_AUTO";
const char TOP_GRAVITY_UUID[] = "19B10011-E8F2-537E-4F6C-D104768A1214";

// -------- Tuning --------
const uint32_t UPDATE_INTERVAL_MS = 50;       // 20 Hz output
const uint32_t STATUS_INTERVAL_MS = 500;      // 2 Hz status updates
const uint32_t TOP_SCAN_TIMEOUT_MS = 4000;    // scan window for top node
const uint32_t RECONNECT_INTERVAL_MS = 3000;  // retry interval if top disconnected
const float FILTER_ALPHA = 0.93f;
const float MIN_ACCEL_NORM = 0.70f;
const float MAX_ACCEL_NORM = 1.30f;

// Axis remap/sign correction.
const int BASE_MAP[3] = {0, 1, 2};
const int TOP_MAP[3]  = {0, 1, 2};
const float BASE_SIGN[3] = {1.0f, 1.0f, 1.0f};
const float TOP_SIGN[3]  = {1.0f, 1.0f, 1.0f};

float baseG[3] = {0.0f, 0.0f, 1.0f};
float topG[3]  = {0.0f, 0.0f, 1.0f};
bool baseFilterReady = false;
bool topPacketReady = false;
uint32_t topSeq = 0;

float baseRoll = 0.0f;
float basePitch = 0.0f;
float topRoll = 0.0f;
float topPitch = 0.0f;

float zeroBaseRoll = 0.0f;
float zeroBasePitch = 0.0f;
float zeroTopRoll = 0.0f;
float zeroTopPitch = 0.0f;

bool sensingEnabled = true;   // Auto-start since no browser UI
bool topConnected = false;
bool zeroReady = false;

uint32_t lastOutput = 0;
uint32_t lastStatus = 0;
uint32_t lastReconnectAttempt = 0;

// ===================== Utility Functions =====================

float wrapDeg(float a) {
  while (a > 180.0f) a -= 360.0f;
  while (a < -180.0f) a += 360.0f;
  return a;
}

void normalise3(float v[3]) {
  float n = sqrt(v[0] * v[0] + v[1] * v[1] + v[2] * v[2]);
  if (n > 0.0001f) {
    v[0] /= n;
    v[1] /= n;
    v[2] /= n;
  }
}

void remapVector(const float in[3], const int mapIdx[3], const float sign[3], float out[3]) {
  out[0] = sign[0] * in[mapIdx[0]];
  out[1] = sign[1] * in[mapIdx[1]];
  out[2] = sign[2] * in[mapIdx[2]];
  normalise3(out);
}

bool readNormalisedAccel(float g[3]) {
  float ax = myIMU.readFloatAccelX();
  float ay = myIMU.readFloatAccelY();
  float az = myIMU.readFloatAccelZ();

  float n = sqrt(ax * ax + ay * ay + az * az);
  if (n < MIN_ACCEL_NORM || n > MAX_ACCEL_NORM) {
    return false;
  }

  g[0] = ax / n;
  g[1] = ay / n;
  g[2] = az / n;
  return true;
}

void updateBaseGravityFilter() {
  float raw[3];
  if (!readNormalisedAccel(raw)) {
    return;
  }

  float mapped[3];
  remapVector(raw, BASE_MAP, BASE_SIGN, mapped);

  if (!baseFilterReady) {
    baseG[0] = mapped[0];
    baseG[1] = mapped[1];
    baseG[2] = mapped[2];
    baseFilterReady = true;
    return;
  }

  baseG[0] = FILTER_ALPHA * baseG[0] + (1.0f - FILTER_ALPHA) * mapped[0];
  baseG[1] = FILTER_ALPHA * baseG[1] + (1.0f - FILTER_ALPHA) * mapped[1];
  baseG[2] = FILTER_ALPHA * baseG[2] + (1.0f - FILTER_ALPHA) * mapped[2];
  normalise3(baseG);
}

void vectorToRollPitch(const float g[3], float &roll, float &pitch) {
  roll  = atan2(g[1], g[2]) * 180.0f / PI;
  pitch = atan2(-g[0], sqrt(g[1] * g[1] + g[2] * g[2])) * 180.0f / PI;
}

float angleBetweenVectors(const float a[3], const float b[3]) {
  float dot = a[0] * b[0] + a[1] * b[1] + a[2] * b[2];
  if (dot > 1.0f) dot = 1.0f;
  if (dot < -1.0f) dot = -1.0f;
  return acos(dot) * 180.0f / PI;
}

void updateAngles() {
  vectorToRollPitch(baseG, baseRoll, basePitch);
  vectorToRollPitch(topG, topRoll, topPitch);
}

// ===================== Status / Telemetry =====================

void writeStatus() {
  String status =
    String("topConnected=") + (topConnected ? "1" : "0") + "," +
    String("sensingEnabled=") + (sensingEnabled ? "1" : "0") + "," +
    String("zeroReady=") + (zeroReady ? "1" : "0") + "," +
    String("baseReady=") + (baseFilterReady ? "1" : "0") + "," +
    String("topSeq=") + String(topSeq) + "," +
    String("millis=") + String(millis());

  statusChar.writeValue(status);
}

void zeroCurrentPose() {
  updateAngles();
  zeroBaseRoll = baseRoll;
  zeroBasePitch = basePitch;
  zeroTopRoll = topRoll;
  zeroTopPitch = topPitch;
  zeroReady = true;
  Serial.println("ZERO completed");
  writeStatus();
}

void writeTelemetry() {
  float baseDeltaRoll = wrapDeg(baseRoll - zeroBaseRoll);
  float baseDeltaPitch = wrapDeg(basePitch - zeroBasePitch);
  float topDeltaRoll = wrapDeg(topRoll - zeroTopRoll);
  float topDeltaPitch = wrapDeg(topPitch - zeroTopPitch);

  float topMinusBaseRoll = wrapDeg(topDeltaRoll - baseDeltaRoll);
  float topMinusBasePitch = wrapDeg(topDeltaPitch - baseDeltaPitch);
  float vectorAngle = angleBetweenVectors(topG, baseG);

  // Build compact fixed-point packet (17 bytes)
  TelemetryPacket pkt;
  pkt.baseRoll         = (int16_t)lroundf(baseRoll * ANGLE_SCALE);
  pkt.basePitch        = (int16_t)lroundf(basePitch * ANGLE_SCALE);
  pkt.topRoll          = (int16_t)lroundf(topRoll * ANGLE_SCALE);
  pkt.topPitch         = (int16_t)lroundf(topPitch * ANGLE_SCALE);
  pkt.topMinusBaseRoll = (int16_t)lroundf(topMinusBaseRoll * ANGLE_SCALE);
  pkt.topMinusBasePitch = (int16_t)lroundf(topMinusBasePitch * ANGLE_SCALE);
  pkt.vectorAngle      = (int16_t)lroundf(vectorAngle * ANGLE_SCALE);
  pkt.topSeq           = (uint16_t)(topSeq & 0xFFFF);
  pkt.status = (uint8_t)(
    (topConnected ? 1 : 0) |
    (sensingEnabled ? 2 : 0) |
    (zeroReady ? 4 : 0)
  );

  telemetryChar.writeValue((uint8_t *)&pkt, sizeof(pkt));

  Serial.print("TELE bR="); Serial.print(baseRoll,2);
  Serial.print(" bP="); Serial.print(basePitch,2);
  Serial.print(" tR="); Serial.print(topRoll,2);
  Serial.print(" tP="); Serial.print(topPitch,2);
  Serial.print(" tmbR="); Serial.print(topMinusBaseRoll,2);
  Serial.print(" tmbP="); Serial.print(topMinusBasePitch,2);
  Serial.print(" vA="); Serial.print(vectorAngle,2);
  Serial.print(" seq="); Serial.println(topSeq);

}

// ===================== Top Node Connection (Auto) =====================

bool connectToTopNode() {
  Serial.println("Auto-scanning for top node...");

  BLE.scanForName(TOP_NODE_NAME);
  uint32_t start = millis();

  while (millis() - start < TOP_SCAN_TIMEOUT_MS) {
    BLE.poll();

    BLEDevice dev = BLE.available();
    if (dev && dev.localName() == TOP_NODE_NAME) {
      BLE.stopScan();
      Serial.println("Found top node. Connecting...");

      if (!dev.connect()) {
        Serial.println("Top connect failed");
        topConnected = false;
        return false;
      }

      if (!dev.discoverAttributes()) {
        Serial.println("Top attribute discovery failed");
        dev.disconnect();
        topConnected = false;
        return false;
      }

      BLECharacteristic ch = dev.characteristic(TOP_GRAVITY_UUID);
      if (!ch) {
        Serial.println("Top gravity characteristic not found");
        dev.disconnect();
        topConnected = false;
        return false;
      }

      if (!ch.canSubscribe() || !ch.subscribe()) {
        Serial.println("Top subscribe failed");
        dev.disconnect();
        topConnected = false;
        return false;
      }

      topPeripheral = dev;
      topGravityCharacteristic = ch;
      topConnected = true;
      topPacketReady = false;
      Serial.println("Top node connected (auto)");
      writeStatus();
      return true;
    }

    delay(20);
  }

  BLE.stopScan();
  topConnected = false;
  Serial.println("Top node not found (scan timeout)");
  return false;
}

void readTopPacketIfAvailable() {
  if (!topConnected) return;
  if (!topGravityCharacteristic.valueUpdated()) return;

  GravityPacket pkt;
  int len = topGravityCharacteristic.readValue((uint8_t *)&pkt, sizeof(pkt));
  if (len != sizeof(pkt)) return;

  float raw[3] = {pkt.gx, pkt.gy, pkt.gz};
  remapVector(raw, TOP_MAP, TOP_SIGN, topG);
  topSeq = pkt.seq;
  topPacketReady = true;
}

// ===================== Command Handler =====================

void handleCommand(String cmd) {
  cmd.trim();
  Serial.print("CMD received: [");
  Serial.print(cmd);
  Serial.print("] len=");
  Serial.println(cmd.length());
  cmd.toUpperCase();

  if (cmd == "START") {
    if (!zeroReady && topPacketReady && baseFilterReady) {
      zeroCurrentPose();
    }
    sensingEnabled = true;
    Serial.println("START");
  } else if (cmd == "STOP") {
    sensingEnabled = false;
    Serial.println("STOP");
  } else if (cmd == "ZERO") {
    if (topPacketReady && baseFilterReady) {
      zeroCurrentPose();
    } else {
      Serial.println("ZERO ignored: waiting for both IMUs");
    }
  } else if (cmd == "RESET_ZERO") {
    zeroReady = false;
    Serial.println("Zero state cleared");
  }

  writeStatus();
}

// ===================== Setup =====================

void setup() {
  Serial.begin(115200);
  uint32_t serialStart = millis();
  while (!Serial && millis() - serialStart < 2000) {}

  Serial.println("\n=== Base Bridge Auto-Pair ===");

  Wire.begin();

  if (myIMU.begin() != 0) {
    Serial.println("Base IMU init failed");
    while (1) {}
  }
  Serial.println("Base IMU: OK");

  // Prime the gravity filter
  for (int i = 0; i < 50; i++) {
    updateBaseGravityFilter();
    delay(10);
  }
  Serial.println("Gravity filter primed");

  if (!BLE.begin()) {
    Serial.println("BLE init failed");
    while (1) {}
  }

  // Setup as peripheral (for ESP32 to connect)
  BLE.setLocalName(BASE_NODE_NAME);
  BLE.setDeviceName(BASE_NODE_NAME);
  BLE.setAdvertisedService(espService);

  espService.addCharacteristic(telemetryChar);
  espService.addCharacteristic(commandChar);
  espService.addCharacteristic(statusChar);
  BLE.addService(espService);

  // Write initial zero packet
  TelemetryPacket zeroPkt;
  memset(&zeroPkt, 0, sizeof(zeroPkt));
  telemetryChar.writeValue((uint8_t *)&zeroPkt, sizeof(zeroPkt));
  writeStatus();
  BLE.advertise();

  Serial.println("Advertising as: " + String(BASE_NODE_NAME));

  // Auto-connect to top node on boot (no PAIR command needed)
  Serial.println("Attempting initial top node connection...");
  connectToTopNode();

  Serial.println("=== Setup complete ===\n");
}

// ===================== Loop =====================

void loop() {
  BLE.poll();

  // Handle incoming commands from ESP32 client
  if (commandChar.written()) {
    String cmd = commandChar.value();
    Serial.println(cmd);
    handleCommand(cmd);
  }

  // Detect top node disconnection
  if (topConnected && !topPeripheral.connected()) {
    topConnected = false;
    topPacketReady = false;
    Serial.println("Top node disconnected");
    writeStatus();
  }

  // Auto-reconnect to top node
  if (!topConnected && millis() - lastReconnectAttempt > RECONNECT_INTERVAL_MS) {
    lastReconnectAttempt = millis();
    connectToTopNode();
  }

  // Read base IMU
  updateBaseGravityFilter();

  // Read top node packets
  readTopPacketIfAvailable();

  // Update angles
  updateAngles();

  // Auto-zero when both IMUs are ready for the first time
  if (!zeroReady && topPacketReady && baseFilterReady) {
    zeroCurrentPose();
  }

  // Send telemetry at 20 Hz
  if (sensingEnabled && zeroReady && topPacketReady && baseFilterReady && millis() - lastOutput >= UPDATE_INTERVAL_MS) {
    lastOutput = millis();
    writeTelemetry();
  }

  // Periodic status update
  if (millis() - lastStatus >= STATUS_INTERVAL_MS) {
    lastStatus = millis();
    writeStatus();
  }
}

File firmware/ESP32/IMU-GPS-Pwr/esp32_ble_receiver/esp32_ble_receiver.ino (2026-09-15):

/*
 * Must change partition to Minimumal SPIFFS
 * esp32_ble_receiver.ino
 * 
 * Combined ESP32-C3 Node: BLE Mast Telemetry + INA219 Power Sensor + GPS Module
 * 
 * This single ESP32-C3 handles three independent data streams:
 *  1. MAST TELEMETRY (header "MAST"):
 *     - Connects to nRF52840 base bridge ("XIAO_BASE_AUTO") via BLE
 *     - Receives 17-byte structured telemetry at ~10 Hz
 *     - Forwards each packet to master via ESP-NOW
 *  2. POWER SENSOR (header "SENS"):
 *     - Reads INA219 shunt monitor via I2C
 *     - Sends voltage/current/power readings at ~1 Hz to master via ESP-NOW
 *  3. GPS Module (header "GPSM"):
 *     - Reads NMEA sentences from GPS module via UART
 *     - ATGM336H GPS module
 * Streams are independent and fault-tolerant:
 *  - Commands from master via ESP-NOW are forwarded to the nRF52840 via BLE write.
 * 
 * Target: ESP32-C3 (or any ESP32 variant)
 * Board package: esp32 by Espressif (Arduino IDE)
 * 
 * Dependencies:
 *  - Adafruit_INA219 library
 *  - ESP32 BLE Arduino (built-in)
 *
 */

#include <Arduino.h>
#include <WiFi.h>
#include <esp_now.h>
#include <Wire.h>
#include <Adafruit_INA219.h>
#include <BLEDevice.h>
#include <BLEUtils.h>
#include <BLEScan.h>
#include <BLEClient.h>
#include <BLEAdvertisedDevice.h>
#include <TinyGPSPlus.h>
#include <HardwareSerial.h>
#include <U8g2lib.h>
#include <MUIU8g2.h>

#define LOGGING 0

// =======================
// PIN CONFIG (adjust for your board)
// =======================
#define I2C_SDA_PIN 3
#define I2C_SCL_PIN 4

// =======================
// ESP-NOW PACKET TEMPLATE (shared protocol with master)
// =======================

// Master node MAC address. Update if master module changes.
uint8_t receiverAddr[] = { 0xac, 0xeb, 0xe6, 0x49, 0xc7, 0xcc };

esp_now_peer_info_t peerInfo;
U8G2_SSD1306_72X40_ER_F_SW_I2C u8g2(U8G2_R0, /* clock=*/6, /* data=*/5, /* reset=*/U8X8_PIN_NONE);

uint32_t str_to_u32(const char s[4]) {
  return ((uint32_t)s[3] << 24) | ((uint32_t)s[2] << 16) | ((uint32_t)s[1] << 8) | ((uint32_t)s[0]);
}

uint16_t checksum16_bytes(const uint8_t *data, size_t len) {
  uint16_t sum = 0;
  for (size_t i = 0; i < len; i++) {
    sum = (uint16_t)((sum << 1) ^ data[i] ^ (sum >> 15));
  }
  return sum;
}

template<typename PayloadT, size_t PAD_BYTES = 0>
struct __attribute__((packed)) PacketTemplate {
  uint32_t header;
  uint16_t counter;
  PayloadT payload;
  uint8_t padding[PAD_BYTES];
  uint16_t chksum;
};

template<typename PacketT>
void clearPacket(PacketT &pkt) {
  memset(&pkt, 0, sizeof(pkt));
}

template<typename PacketT>
void finalizePacket(PacketT &pkt, uint32_t header, uint16_t counter) {
  pkt.header = header;
  pkt.counter = counter;
  pkt.chksum = checksum16_bytes(
    (const uint8_t *)&pkt.counter,
    sizeof(pkt) - sizeof(pkt.header) - sizeof(pkt.chksum));
}

template<typename PacketT>
void sendPacket(const PacketT &pkt) {
  esp_now_send(receiverAddr, (const uint8_t *)&pkt, sizeof(pkt));
}

void incrementCounter(uint16_t &counter) {
  counter = (counter == 65535) ? 1 : counter + 1;
}

// =======================
// STREAM 1: MAST TELEMETRY (BLE -> ESP-NOW, header "MAST")
// =======================

// BLE telemetry packet from nRF52840 base bridge (17 bytes)
struct __attribute__((packed)) MastPayload {
  int16_t  baseRoll;           // fixed-point ×100
  int16_t  basePitch;
  int16_t  topRoll;
  int16_t  topPitch;
  int16_t  topMinusBaseRoll;
  int16_t  topMinusBasePitch;
  int16_t  vectorAngle;
  uint16_t topSeq;
  uint8_t  status;             // bit0=topConnected, bit1=sensingEnabled, bit2=zeroReady
};
// sizeof(MastPayload) = 17 bytes

// ESP-NOW packet: header(4) + counter(2) + payload(17) + padding(3) + chksum(2) = 28 bytes
using MastPacket = PacketTemplate<MastPayload, 3>;

uint32_t MAST_HEADER;
uint16_t mastCounter = 1;

// =======================
// POWER SENSOR (I2C -> ESP-NOW, header "SENS")
// =======================

struct __attribute__((packed)) SensorPowerPayload {
  float shuntvoltage;   // 4 bytes
  float busvoltage;     // 4 bytes
  float current_mA;     // 4 bytes
  float loadvoltage;    // 4 bytes
  float power_mW;       // 4 bytes
};
// sizeof(SensorPowerPayload) = 20 bytes

// ESP-NOW packet: header(4) + counter(2) + payload(20) + padding(0) + chksum(2) = 28 bytes
using SensorPowerPacket = PacketTemplate<SensorPowerPayload, 0>;

uint32_t SENS_HEADER;
uint16_t sensCounter = 1;

Adafruit_INA219 ina219;
bool ina219Available = false;
uint32_t lastPowerRead = 0;
const uint32_t POWER_INTERVAL_MS = 1000;  // 1 Hz

// =======================
// GPS MODULE (UART -> ESP-NOW, header "GPSM")
// =======================

struct __attribute__((packed)) GPSPayload {
  int32_t latitude;    // fixed-point ×1e7
  int32_t longitude;   // fixed-point ×1e7
  int16_t altitude;    // meters
  uint16_t speed;      // km/h
  uint16_t course;     // degrees ×100
  uint16_t hdop;       // cm
  uint8_t satellites;  // number of satellites
};
// Total size = 4+4+2+2+2+2+1 = 17 bytes

// ESP-NOW packet: header(4) + counter(2) + payload(17) + padding(3) + chksum(2) = 28 bytes
using GPSPacket = PacketTemplate<GPSPayload, 3>;

uint32_t GPS_HEADER;
uint16_t gpsCounter = 1;
uint32_t last_gps_read = 0;
TinyGPSPlus gps;
static const int RXPin = 20, TXPin = 21;
static const uint32_t GPSBaud = 9600;

HardwareSerial ss(1);

void readandSendGPS() {
  // Feed ALL available GPS data to TinyGPSPlus
  while (ss.available()) {
    gps.encode(ss.read());
  }

  // Send once per second
  if (millis() - last_gps_read < 1000) return;
  last_gps_read = millis();

  GPSPacket pkt;
  clearPacket(pkt);

  pkt.payload.latitude  = (int32_t)(gps.location.lat() * 10000000.0);
  pkt.payload.longitude = (int32_t)(gps.location.lng() * 10000000.0);
  pkt.payload.altitude  = (int16_t)gps.altitude.meters();
  pkt.payload.speed     = (uint16_t)gps.speed.kmph();
  pkt.payload.course    = (uint16_t)(gps.course.deg() * 100.0);
  pkt.payload.hdop      = (uint16_t)gps.hdop.hdop();
  pkt.payload.satellites = (uint8_t)gps.satellites.value();

  finalizePacket(pkt, GPS_HEADER, gpsCounter);
  incrementCounter(gpsCounter);
  sendPacket(pkt);
#if LOGGING 
  Serial.println(pkt.payload.latitude);
  Serial.println(pkt.payload.altitude);
  Serial.println(pkt.payload.satellites);
#endif
}


// Command reception from master node via ESP-NOW.
// Master sends raw ASCII bytes (e.g., "START", "STOP", "ZERO", "RESET_ZERO").
static volatile bool pendingCommand = false;
static char commandBuffer[32];
static size_t commandLength = 0;

void onESPNowRecv(const esp_now_recv_info_t *info, const uint8_t *incomingData, int len) {
  if (len <= 0 || len > 30) return;

  memcpy(commandBuffer, incomingData, len);
  commandBuffer[len] = '\0';
  commandLength = len;
  pendingCommand = true;

#if LOGGING
  Serial.printf("ESP-NOW cmd recv: %s\n", commandBuffer);
#endif
}
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

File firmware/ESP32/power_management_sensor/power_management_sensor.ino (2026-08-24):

#include <esp_now.h>
#include <esp_wifi.h>
#include <WiFi.h>
#include <ADS8688.h>

#define SHOW_SUCCESS 0
#define PIN_CS 7
#define PIN_SCK 6
#define PIN_MOSI 5
#define PIN_MISO 4

#define DEFAULT_OFFSET 0
#define DIVIDER_OFFSET 0

#define ADS8688_SPI_CLOCK 20000000
#define SAMPLING_RATE 1200
//#define SAMPLING_RATE 10
#define PACKET_SIZE 6

ADS8688 adc(PIN_CS, PIN_SCK, PIN_MOSI, PIN_MISO);

uint32_t header;  // 1347896658
char role[4] = { 'P', 'W', 'E', 'R' };

struct __attribute__((packed)) Packet {
  uint32_t header;
  uint16_t counter;
  uint32_t timediff_us;
  uint16_t readings[8];
  uint16_t chksum;
};
Packet bulkPacket[PACKET_SIZE];

const uint8_t R1_SIZE = 6;
const uint8_t R5_SIZE = 2;
const uint8_t r1_pins[R1_SIZE] = { 0, 1, 2, 3, 4, 5 };  // Direct HE sensor reading
const uint8_t r5_pins[R5_SIZE] = { 6, 7 };              // Battery voltage stepped down

uint16_t raw_readings[8];
uint32_t prevTime_us;
uint16_t counter = 1;
uint16_t packet_position = 0;
uint16_t timer_start;

uint32_t str_to_u32(const char s[4]) {
  return ((uint32_t)s[3] << 24) | ((uint32_t)s[2] << 16) | ((uint32_t)s[1] << 8) | ((uint32_t)s[0]);
}

uint16_t additive_chksum(uint16_t *readings, uint16_t counter) {
  uint16_t sum = counter;
  for (int i = 0; i < 8; i++) {
    sum ^= readings[i] << (i + 1);
  }
  return sum;
}

bool init_ADS8688() {
  header = str_to_u32(role);

  for (int i = 0; i < R1_SIZE; i++) {
    adc.setChannelRange(r1_pins[i], R1);
  }

  for (int i = 0; i < R5_SIZE; i++) {
    adc.setChannelRange(r5_pins[i], R5);
  }

  adc.setChannelSequence(0xFF);  // or 0b11111111 (not x but b)
  adc.setSampleRate(SAMPLING_RATE);
  adc.autoRst();

  SPI.beginTransaction(SPISettings(ADS8688_SPI_CLOCK, MSBFIRST, SPI_MODE1));

  prevTime_us = micros();
  timer_start = millis();
  return true;
}

uint8_t boadcastAddr[] = { 0xac, 0xeb, 0xe6, 0x49, 0xc7, 0xcc };
esp_now_peer_info_t peerInfo;

bool init_ESP_NOW() {
  if (esp_now_init() != ESP_OK) {
    Serial.println("ESP now failed to initialise");
    return false;
  }

  esp_now_register_send_cb(esp_now_send_cb_t(onESPNowSent));

  memcpy(peerInfo.peer_addr, boadcastAddr, 6);

  peerInfo.channel = 0;
  peerInfo.encrypt = false;

  if (esp_now_add_peer(&peerInfo) != ESP_OK) {
    Serial.println("Failed to add receiving device");
    return false;
  }

  return true;
}

void onESPNowSent(const uint8_t *mac_addr, esp_now_send_status_t status) {
#if SHOW_SUCCESS
  if (status == ESP_NOW_SEND_SUCCESS) {
    Serial.println("Delivery Success")
  }
#endif
  if (status != ESP_NOW_SEND_SUCCESS) {
    Serial.println("Delivery Fail");
  }
}

int channel_offsets[8] = { 0 };
const uint16_t R1_OFFSET_THRESHOLD = 200;
const uint16_t R5_OFFSET_THRESHOLD = 200;
const uint8_t OFFSET_DIFF_THRESHOLD = 50;

void setup() {
  Serial.begin(2000000);

  WiFi.mode(WIFI_STA);

  while (!init_ESP_NOW()) {
    delay(100);
  }

  while (!init_ADS8688()) {
    delay(100);
  }
  Serial.println("Finished setup");
}

void IRAM_ATTR loop() {
  while (packet_position < PACKET_SIZE) {
    adc.waitForSample();  // Limit sampling rate. If sampling rate set to 0, no effect

    uint32_t now_us = adc.readAllChannels(raw_readings);

    Packet &currPkt = bulkPacket[packet_position];
    currPkt.counter = counter;
    currPkt.timediff_us = now_us - prevTime_us;

    for (int i = 0; i < R1_SIZE; i++) {
      uint8_t idx = r1_pins[i];
      int diff = raw_readings[idx] - 32768;
      if (abs(diff) < R1_OFFSET_THRESHOLD) {
        if (channel_offsets[idx] == 0) {
          channel_offsets[idx] = diff;
        } else if (abs(diff - channel_offsets[idx]) < OFFSET_DIFF_THRESHOLD) {
          // Update offset if the new reading is close to the current offset
          channel_offsets[idx] = (channel_offsets[idx] + diff) / 2;
        }
      }

      uint16_t raw = raw_readings[idx];
      int total_offset = DEFAULT_OFFSET + channel_offsets[idx];
      if (raw < total_offset) {
        raw = 0;
      } else if (raw > 65535 - total_offset) {
        raw = 65535;
      } else {
        raw -= total_offset;
      }
      // Ranges from -5.12 to +5.12V
      // Add a function to recalculate offset when close to 0 reading
      currPkt.readings[idx] = raw;
      //Serial.print(idx); Serial.print(" "); Serial.print(raw_readings[idx]); Serial.print(" "); Serial.print(diff); Serial.print(" "); Serial.print(channel_offsets[idx]); Serial.print(" "); Serial.println(raw);
    }

    for (int i = 0; i < R5_SIZE; i++) {
      uint8_t idx = r5_pins[i];

      if (raw_readings[idx] < R5_OFFSET_THRESHOLD) {
        if (channel_offsets[idx] == 0) {
          channel_offsets[idx] = raw_readings[idx];
        } else if (abs((int)raw_readings[idx] - channel_offsets[idx]) < OFFSET_DIFF_THRESHOLD) {
          // Update offset if the new reading is close to the current offset
          channel_offsets[idx] = (channel_offsets[idx] + raw_readings[idx]) / 2;
        }
      }

      uint16_t raw = raw_readings[idx];
      uint16_t total_offset = DEFAULT_OFFSET + channel_offsets[idx];
      if (raw < total_offset) {
        raw = 0;
      } else {
        raw -= total_offset;
      }

      currPkt.readings[idx] = raw;
    }

    currPkt.chksum = additive_chksum(currPkt.readings, counter);
    currPkt.header = header;
    prevTime_us = now_us;

    if (counter == 65535) {  // Needs to restart from 1
      counter = 1;
    } else {
      counter += 1;
    }

    packet_position += 1;
  }

  // Write to ESP Now
  esp_err_t transmission_result = esp_now_send(boadcastAddr, (uint8_t *)&bulkPacket, sizeof(bulkPacket));

  if (transmission_result != ESP_OK) {
    taskYIELD();
    transmission_result = esp_now_send(boadcastAddr, (uint8_t *)&bulkPacket, sizeof(bulkPacket));
  }

  /*
  if (transmission_result != ESP_OK) {
    Serial.println("Failed to queue");
  }
  */

#if SHOW_SUCCESS
  if (transmission_result == ESP_OK) {
    Serial.println("Successfully queued for sending");
  }
#endif

  packet_position = 0;  // Manually reset to 0 index
  taskYIELD();
}

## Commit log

2026-05-14 setup for react frontend instead of pure express
    [ocv_soc_dict.csv]
2026-05-17 sqlite setup
    [RC_values.csv, battery_state.csv, ocv_soc_dict.csv]
2026-05-18 kalman gain partial implementation
    [battery_state.csv]
2026-06-03 fix model
    [battery_state.csv]
2026-06-04 test data implemetation
    [data_20260601-153543_part_3.csv]
2026-06-09 filter test update
    [data_20260601-153543_part_3.csv, test_file_1.csv, test_file_13.csv]
2026-06-14 LiFePO4 data
    [battery_state.csv]
2026-06-17 working filter
    [battery_state.csv, data_20260612-153706_part_9.csv, data_20260612-163712_part_0.csv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]
2026-06-19 tune filter 1
    [data_20260612-164950_part_9.csv]
2026-06-21 fix nav bar and clean log statements
    [esp8266_json_code.ino]
2026-06-23 tuned alt batt
    [data_20260612-164950_part_9.csv]
2026-06-23 fix wrong battery rc mapping
2026-06-25 adjust chart ui
    [battery_state.csv]
2026-06-26 concurrently yarn script
    [data_20260612-164950_part_9.csv, test_file_1.csv, test_file_13.csv]
2026-06-26 modularise power byte parser
2026-06-30 fix serial parser not skipping on checksum fail
    [data_20260612-164950_part_9.csv]
2026-06-30 main batt test data
    [SOCSensor_part13.csv]
2026-07-04 fixed formatting error on display switch
2026-07-07 reduce test size
    [SOCSensor_part13.csv]
2026-07-07 update battery font color
2026-07-16 Implemented aluxury power consumption tracking
2026-07-16 Integrate IMU sensor (WIP)
2026-07-20 initialise IMU code modification
2026-07-22 update device type
2026-07-29 Implement test data selection
    [SOCSensor_part13.csv, data_20260612-153706_part_9.csv, data_20260612-163712_part_0.csv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]
2026-08-04 im tired
2026-08-05 Remove sqlite recovery file
    Causes database init issue if shared across devices
2026-08-15 Generated IMU sensor code for ESP now comms
2026-08-22 adaptation of imu firmware to framework
2026-08-23 IMU integration complete
2026-08-24 Fix strain gauge esp mac address
    [esp32_ble_receiver.ino, serialReader.js]
2026-08-24 refactor imu and strain to mirror power implementation
2026-08-24 remove unused strain calibration tab
2026-08-24 refactor backend database to follow power
2026-08-31 Included schematic design
    [.step, BOM-Sensor Reader V4.csv, Final Design.kicad_pcb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]
2026-09-02 Reorder file
    [.step, Ads8688 Enclosure.3mf, BOM-Sensor Reader V4.csv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]
2026-09-04 stupid arduino
    [External gps sensor enclosure.3mf]
2026-09-05 update image
    [External gps sensor enclosure.3mf]
2026-09-15 Complete gps integration
    [External gps sensor enclosure.3mf]
